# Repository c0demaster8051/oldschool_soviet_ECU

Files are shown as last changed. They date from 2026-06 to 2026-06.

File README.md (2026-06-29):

# ЭБУ на советской элементной базе

Идея сделать такой девайс на древней элементной базе появилась исключительно из любви к искусству,
Хотелось собрать что-то красивое, применимое в реальной жизни и немного подкачать скилл.
Мне нравятся простые и дубовые детали в красивых керамических корпусах, но собирать устройство
которое будет просто лежать на полке и собирать пыль (как новодельные сборки ZX Spectrum) мне не интересно.
Считаю что вещь должна работать и приносить пользу.

### Внимание!

Блок уже давно спроектирован и собран, работает на машине уже более года, просто сейчас решил выложить его
чтобы не потерять схемы и код проекта (как обычно раскиданный по разным дискам и флешкам). Постепенно я буду
приводить схемы к понятному для окружающих виду и заливать сюда.

### Коротко о возможностях:

- Максимальные обороты:  
10000 для задающего диска 60-2 (ВАЗ, ЗМЗ и др.), до 15000 для диска 36-2 (toyota)

- Точность управления:
дискретность времени открытия форсунок и выдачи импульса зажигания - 1 мкс.
Момент выдачи искры определяется аппаратно отдельной схемой, которую контроллер просто "взводит"
перед использованием, благодаря чему момент зажигания выдаётся абсолютно точно независимо от
времени реакции контроллера.

- Аналоговые входы - 5 каналов АЦП с разрядностью 11 бит, один из которых с устройством выборки и хранения
для датчика абсолютного давления, выполняет измерение с жёсткой привязкой к положению коленвала. 
Оставшиеся 4 канала:  
Датчик положения дросселя,  
Напряжение бортсети (для коррекции динамической производительности форсунок от напряжения питания),  
Датчик температуры двигателя,  
Датчик температуры воздуха

- Дискретные выходы:  
4 линии на шаговый РХХ,  
4 независимых линии для управления реле бензонасоса и прочими механизмами

### Hardware:

Из-за сильно ограниченных вычислительных способностей элементной базы тех лет, блок пришлось делать
на двух контроллерах, ведущий и ведомый, далее будем называть их master и slave.

Slave контроллер выполняет самую сложную работу в реальном времени, такую как синхронизация на задающий
диск шкива коленвала, выдача импульсов зажигания, открытие форсунок с учётом фазы впрыска и взятие значения
с датчика абсолютного давления с жёсткой привязкой к положению коленвала. Программа для слейва написана
на ассемблере, вылизана по тактам и микросекундам, благодаря чему со стандартным задающим диском 60-2 (ВАЗ, ЗМЗ)
блок успевает корректно управлять двигателем до 10000 оборотов в минуту. С диском 36-2 максимальные обороты
увеличиваются до 15000.

Таймеры управляющие зажиганием и форсунками тактируются с частотой 1 МГц, соответственно точность момента
искрообразования и длительности впрыска получается 1 микросекунда. Для сравнения на ВАЗовском ЭБУ "Январь"
точность времени впрыска и момента зажигания 6 мкс.

Slave общается с мастером через отдельный маленький буфер на дискретной логике, постоянно получая от мастера
время впрыска, момент зажигания, фазу впрыска. При старте блока slave получает фиксированные параметры,
обычно не изменяемые в процессе работы блока, например фазу измерения значения ДАД, базовые настройки
синхронизации (такие как полное число зубов шкива, число пропущенных, порог срабатывания при поиске пропуска).
Обратно он отдаёт измеренное время оборота коленвала в микросекундах и некторые флаги.

Мастер в свою очередь выполняет расчёт топливоподачи и зажигания асинхронно от вращения двигателя,
с фиксированной частотой 122 Гц (частота получения результата измерения канала ДАД). В конце расчёта он
передаёт ведомому (slave) контроллеру актуальные значения по топливу и зажиганию. Из-за фиксированной
и относительно небольшой скорости выполнения расчётов программа для мастера написана на СИ.

Блок состоит из 4 плат. Детальное описание каждой, исходные файлы плат и исходники прошивок (для плат с
контроллерами) лежат в отдельных папках, каждая под свою плату. Содержимое папок будет постоянно дополняться,
на данный момент можно примерно понять конструкцию и принцип дествия.

Для смельчаков и просто странных личностей, решивших собрать плод моего больного воображения:
дождитесь когда я подготовлю полное описание)) будут gerber файлы, 3D модели корпуса и подробная инструкция
по сборке и прошивке.

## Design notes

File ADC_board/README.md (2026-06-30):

# Плата АЦП и буфера межконтроллерного обмена

<p align="center">
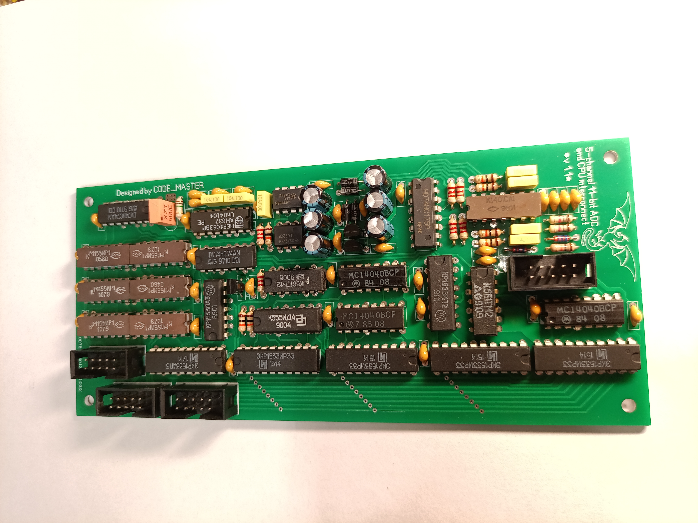
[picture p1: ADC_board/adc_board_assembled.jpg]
Assebled
  
</p>

На данной плате расположен 5-канальный АЦП и буфер для взаимодействия
master и slave контроллеров, обмен с ведущим процессором выполняется по
классической 8-разрядной мультиплексированной шине адреса/данных. Адреснужного
регистра защёлкивается линией управления ALE, после чего можно выполнять
чтение или запись в регистры.

### Описание АЦП:

АЦП интегрирующего типа, разрядностью 11 бит с диапазоном входных напряжений
от GND до VCC. накопление результата длится 2049 тактов, при частоте тактирования
всей схемы 250 КГц АЦП выдаёт результат со скоростью 122 герц. Тактовый генератор
собран на керамическом резонаторе 500 КГц, далее эта частота делится на 2.
АЦП имеет один общий счётчик циклов измерения на микросхеме CD4040 и два
отдельных накопителя импульсов с интеграторов тоже на CD4040. По переполнению
счётчика циклов измерения результат из двух накопителей пишется в выходные
регистры 1533ир33.

Один из накопителей - выделенный канал АЦП для датчика абсолютного давления,
с аналоговой схемой sample&hold для фиксации мгновенного значения сигнала.
Свежий результат измерения с этого канала доступен в каждом новом прерывании от АЦП.
Второй накопитель обслуживает 4 мультиплексных канала. Каждый из этих каналов имеет
свой непрерывно тактируемый интегратор и счётчик, последовательно переключающий каналы.
Мультиплексный канал при помощи цифрового коммутатора выбирает с какого из интеграторов
он будет накапливать импульсы.

Мультиплексных канала 4, поэтому их фактическая частота опроса - 122/4 = 30.5 Гц.
Результат измерения обоих каналов доступен через три 8-битных регистра, в которых
11 бит отводится под результат выделенного АЦП, 11 бит для мультиплексного и 2 бита
для указания номера только что измеренного мультиплексного канала.

Адрес и формат данных в регистрах:
0x00 - младшие 8 бит мультиплексного канала целиком.
0x01 - старшие 3 бита этого регистра (биты 5, 6, 7) являются старшими битами
результата мультиплексного канала. Биты 3 и 4 - номер только что измеренного
мультиплексного канала. Младшие 3 бита (0, 1, 2) - старшие для выделенного канала.
0x02 - младшие 8 бит выделенного канала.

### Описание буфера межконтроллерного обмена:

Буфер обмена представляет собой 6 сдвиговых 4-битных регистрана микросхемах 74ls95,
суммарной ёмкостью 3 байта. В зависимости от режима блок данных сдвигается или ведущим
(master) контроллером, параллельным сдвигом, по половинке байта в 6 подходов, или
последовательно по одному биту ведомым (slave) контроллером. Режим работы буфера выбирается
slave контроллером, и переключается в последовательный режим при обращении slave к буферу.

После обмена ведомый контроллер переводит буфер в параллельный режим, вызывая этим
прерывание у ведущего, и оставляет его в этом режиме до появления сигнала готовности
новых данных от ведущего. Для чтения данных из буфера master контроллером отведён адрес
0x03, байты вычитываются из буфера 4-битными посылками, расположенными в старших битах
на шине данных. Первым чтением получаем из буфера младшую половину байта (сдвигаем
результат чтения на 4 бита вправо), вторым чтением получаем старшую половину (обнулить
в результате чтения младшие 4 бита и наложить на предыдущий считанный результат.)
аналогичным образом читаются оставшиеся 2 байта, суммарно 6 циклов чтения.

Запись в буфер выполняется аналогичным образом, но по адресу 0x02, сначала записываемый
байт сдвигается влево на 4 бита, пишется в порт, после чего байт пишется в порт без сдвига,
и так аналогично для оставшихся двух байт.

Чтобы подать slave контроллеру сигнал о готовности данных - необходимо выполнить пустую
запись по адресу 0x03, этим мы взводим триггер, который выдаёт ведомому активный уровень
на линии MRDY. После этого нам остаётся ждать, пока ведомый выйдя из очередного прерывания
увидит этот запрос, займёт буфер, выполнит обмен данными и в конце переводёт буфер обратно
в параллельный режим, тем самым вызвав прерывание у ведущего. Если не сообщать slave контроллеру
о готовности - данные так и будут лежать в буфере и мы можем прочитать их обратно,
это может быть полезно для самотестирования схемы при запуске устройства.

## Описание разъёмов платы:

<p align="center">
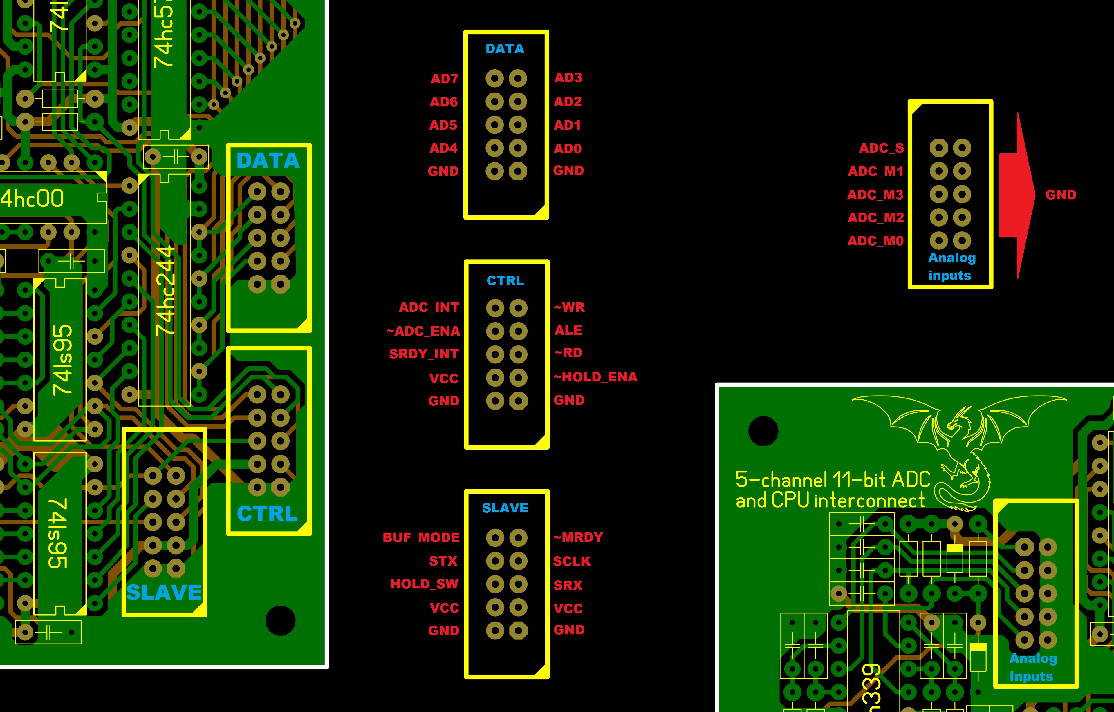
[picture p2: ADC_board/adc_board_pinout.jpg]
Распиновка
  
</p>

### Разъёмы DATA и CTRL идут на плату master контроллера

- Линии AD0-AD7 - мультиплексная шина адреса/данных

- ADC_INT - прерывание АЦП. При непрерывной работе АЦП (ADC_ENA==0)
в процессе измерения находится в высоком уровне, после чего по нулю
длительностью 4 мкс происходит запись в выходные регистры АЦП.
С переходом из 0 в 1 начинается новый цикл измерения. Нарастающий фронт
этого сигнала вызывает прерывание у ведущего процессора.
При непрерывной работе измерения выполняются со стабильной частотой 122 Гц,
мультиплексные входы из-за последовательного опроса отдают данные с частотой
в 4 раза ниже, примерно 30.5 раз в секунду.

- ~ADC_ENA - сигнал разрешения работы АЦП, активный уровень 0.
При снятии этого сигнала АЦП  выполняет полное измерение, после чего
выход ADC_INT принимает уровень 0, в котором находится до очередного
разрешения работы АЦП. Отключение АЦП позволяет незначительно снизить
потребление тока, т.к. на него завязана схема полученния дополнительных
питающих напряжений для входных ключей, усилителей и компараторов.

- SRDY_INT - прерывание от ведомого процессора. Этот-же сигнал выведен
на другой разъём как BUF_MODE. При чтении ведомым процессором данных из буфера,
этим сигналом буфер переводится в последовательный режим, после чего 3 байта
данных сдвигаются и побитово читаются ведомым процессором. После чтения данных
и (опционально) записи в буфер своих - сигнал переводится в 1, переводя буфер в
параллельный режим и сообщая ведущему процессору о готовности.
Нарастающий фронт этого сигнала вызывает прерывание у ведущего процессора.

- ~WR - сигнал записи для параллельной шины, активный уровень 0.

- ALE - сигнал защёлкивания адреса в дешифратор, запись длится в течении уровня 1.

- ~RD - сигнал чтения для параллельной шины, активный уровень 0.

- ~HOLD_ENA - Сигнал разрешения работы схемы sample&hold для выделенного канала АЦП,
при работе которой сигнал берётся с привязкой к положению коленвала. Активный уровень 0.
При отключении выделенный вход АЦП подключается аналоговым коммутатором напрямую.

### Разъём SLAVE идёт на плату ведомого контроллера.

- BUF_MODE - то-же что и SRDY_INT, смотри описание выше. Схема с открытым коллектором.
Долгое удержание этой линии в состоянии 0 ведомым процессором (в случае его зависания)
или ведущим процессором вызывает запуск простейшего аналогового watchdog таймера
на плате ведомого процессора, вызывая его сброс и заставляя отпустить эту линию.

- STX - последовательный выход данных от ведомого процессора для записи в буфер.

- HOLD_SW - фиксация уровня сигнала схемой sample&hold ведомым процессором
в заданный угол поворота коленвала. Выполняется простой переход этой линии в противоположное
состояние, меняя местами одну группу конденсаторов, непрерывно фиксирующих входной сигнал,
с другой группой, чьё "зафиксированное" напряжение подаётся на выделенный вход АЦП.

- ~MRDY - сигнал о готовности команды и данных в буфере на ведомый процессор от ведущего,
активный уровень 0. В фоновом режиме между прерываниями ведомый процессор опрашивает этот сигнал,
и по его активации переводит буфер в последовательный режим для взаимодействия с ним.

- SCLK - тактирование последовательных данных от ведомого процессора. Сдвиг данных в буфере
выполняется по спадающему фронту этого сигнала.

- SRX - последовательный вход данных ведомого процессора для чтения из буфера.

### Разъём Analog inputs идёт на силовую плату.

- ADC_S - выделенный вход под датчик абсолютного давления, с фиксацией сигнала схемой sample&hold.

- ADC_M1 -  мультиплексный вход под датчик положения дросселя.

- ADC_M3 - мультиплексный вход для контроля напряжения бортсети. Делитель напряжения находится на
силовой плате. Одна дискрета АЦП соответствует 10 милливольтам входного напряжения. Для примера,
значение АЦП 1260 будет соответствовать 12.6 вольтам бортсети.

- ADC_M2 - мультиплексный вход с подтяжкой 1 КОм для терморезистора датчика температуры двигателя.

- ADC_M0 - мультиплексный вход с подтяжкой 1 КОм для терморезистора датчика температуры воздуха.

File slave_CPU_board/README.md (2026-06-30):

# Плата slave контроллера

<p align="center">
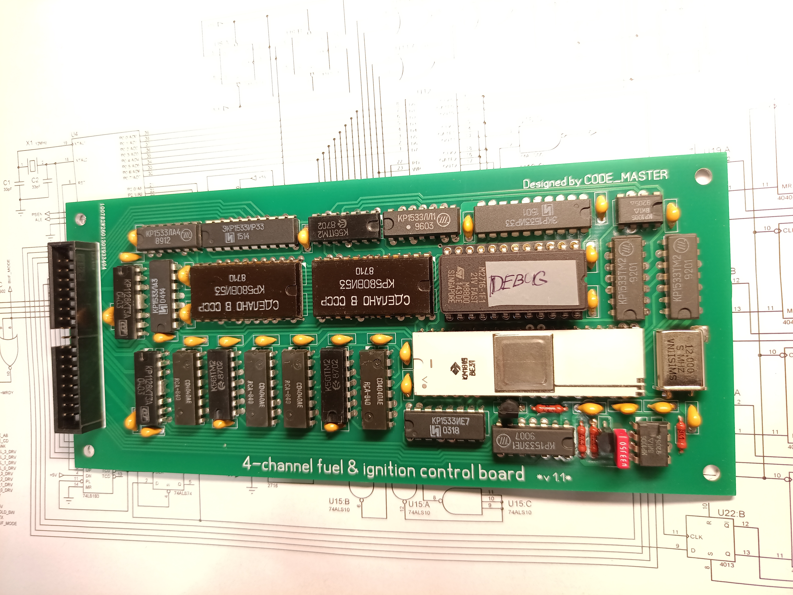
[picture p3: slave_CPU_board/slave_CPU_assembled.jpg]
Assebled
  
</p>

Плата ведомого контроллера собрана на intel 8031 (русский аналог 1816ве31 или его КМОП
версия 1830ве31) с тактовой частотой 12 МГц. Из основного имеет на борту 2 Кб внешней
ПЗУ памяти программ, 2 микросхемы программируемых таймеров intel 8253 (русский аналог 580ВИ53),
работающих с тактовой частотой 1 МГц (точность отсчёта времени соответственно 1 мкс) и таймеры
открытого состояния ключей зажигания на мелкой логике. Все остальные элементы будут описаны далее.

### Алгоритм синхронизации по ДПКВ

Самый главный элемент платы - схема синхронизации на ДПКВ. Вход сигнала ДПКВ подключен
к триггеру шмитта на таймере ne555, для лучшей помехоустойчивости. Инвертированный
сигнал с выхода триггера идёт на постоянно тактируемый D-триггер 1533тм2, который
синхронизирует фронты входного сигнала с тактовым сигналом, в качестве которого используется
сигнал ALE контроллера с частотой 2 МГц. Следующий триггер подключен тактовым входом к выходу
первого триггера, и ставится в единицу при нарастающем фронте входного сигнала, но при этом
асинхронный вход R этого триггера подключен к ALE, таким образом, установившись в состояние 1
по нарастающему фронту ALE, через 0.25 микросекунды триггер сбрасывается низким уровнем на ALE.
В результате этот триггер даёт короткие положительные импульсы по нарастающему фронту
входного сигнала (или соответственно по спадающему перед формирователем на ne555).
Эти короткие импульсы используются схемой формирования сигнала на зажигание, которая
будет описана далее.

Синхронизированный с сигналом ALE входной сигнал идёт на тактовый вход D-триггер соседней
микросхемы 1533тм2, инверсный выход которого подключен на его вход данных. Таким образом
каждый положительный фронт входного сигнала прямой и инверсный выходы триггера меняют
состояние на противоположное. Эти выходы идут на входы прерываний контроллера INT0 и INT1.
Эти входы настроены так, что низкий уровень на них останавливает внутренний таймер контроллера
с соответствующим номером и вызывает прерывание. Таймеры считают с частотой 1 МГц.
Для примера, спадающий фронт на входе INT0 вызывает соответствующее прерывание, а низкий
уровень на нём моментально останавливает таймер 0. В свою очередь противоположный сигнал на INT1
своим высоким уровнем запускает таймер 1. В данной ситуации в прерывании INT0 контроллер считывает
период из остановленного таймера 0 и обнуляет его, чтобы при очередном фронте сигнала ДПКВ
запустить этот таймер и считать результат измерения из таймера 1 (они работают по очереди).

Каждый новый измеренный период сравнивается с предыдущим, и в случае если только что измеренный
период намного больше предыдущего - значит мы наткнулись на пропуск зубов задающего диска коленвала,
и зуб вызвавший это прерывание, первый после пропуска, будет точкой отсчёта с номером 0.

В каждом следующем прерывании счётчик зубов увеличивается, и выполняется проверка, следует ли
исполнить какое-либо действие. Для примера, такими действиями является впрыск топлива, переключение
схемы sample&hold для АЦП датчика давления, или подготовка к выдаче импульса зажигания.
на ВАЗовском диске с формулой 60-2 зубья идут через каждые 6 градусов поворота коленвала,
соответственно с такой дискретностью идёт исполнение событий по ходу вращения двигателя.
Дальнейшее описание этих событий начнём от простого к сложному.

### Sample&hold

Самое простое - переключение схемы фиксации уровня сигнала датчика давления. Для этого используется
бит 7 регистра GPIO, в качестве которого используется 1533ир33, подключенный к внешней шине данных.
Изменение уровня на противоположное переключает группы конденсаторов на плате АЦП, подключая ко входу
компаратора АЦП конденсаторы со свежим "зафиксированным" уровнем сигнала.

### Синхронизированный впрыск топлива

Следующее по сложности - впрыск топлива. Для этого используются таймеры с номерами 1 и 2 микросхем
580ви53, с двух микросхем соответственно доступно 4 раздельных независимых выхода на форсунки. Запуск
этих таймеров на выдачу импульса открытия форсунок выполняется строго синхронно по шкиву, в зависимости
от режима впрыска (фазированный или попарный) запускается по одному или сразу по 2 таймера. Таймеры
настроены в такой режим, что открывают форсунку и считают время сразу после записи периода в таймер.
Дешифрация адреса для обращения к таймерам устроена таким образом, что можно одним разом выполнить
запись сразу в 2 таймера для попарного режима впрыска.

### Асинхронный впрыск

Таймер 0 одной из микросхем используется отдельно для асинхронного впрыска, и подключен на входы
сразу к 4 промежуточным элементам И-НЕ, благодаря чему способен открывать сразу все форсунки
при запуске отсчёта. Асинхронный впрыск выполняется без привязки к положению коленвала,
сразу-же при поступлении команды с ведущего процессора.

### Управление системой зажигания

Самая сложная часть - система зажигания. Таймер 0 одной из 580ви53 используется для точного отсчёта
смещения от зуба ДПКВ для выдачи импульса зажигания. Для выбора момента зажигания используется
номер зуба шкива и смещение относительно него с точностью 1/256 часть от периода между зубами.
Запись периода в этот таймер не запускает его сразу, а всего-лишь взводит схему разрешения счёта,
в момент записи блокирующую таймер нулём по входу GATE, и которая в свою очередь аппаратно запускает
таймер единицей по входу GATE на ближайшем импульсе ДПКВ. Таймер сразу-же начинает считать, и в конце
счёта выдаёт импульс зажигания, запуская отдельные следующие за ним выходные таймеры на рассыпухе
(микросхемы 561тм2 и 561ие20). Контроллер своими линиями порта P1 может управлять длительностью этого
импульса (старшая тетрада P1 подключена к счётчику с переменным коэффициентом деления) и определяет,
на какие из 4 выходов пойдёт этот импульс зажигания (Младшая тетрада P1). Таким образом, аппаратная
привязка запуска таймера зажигания позволяет устранить задержки и достичь высокой угловой и временной
точности импульса зажигания. Для примера, 1 микросекунда (дискретность отсчёта таймера) на 10 тысячах
оборотов коленвала в минуту будет соответствовать его углу поворота на 0.06 градуса.

### Цепи согласования с остальной схемой

Из дополнительной обвязки на плате имеются силовые ключи 1128кт3 для управления ключами форсунок
и выдачи импульсов с напряжением бортсети на коммутаторы, простейшая схема сброса контроллера и
по совместительству watchdog таймер на ещё одной микросхеме ne555, защёлка адреса на регистре 1533ир33,
схема согласования контроллера с буфером межпроцессорного обмена, предделитель тактовой частоты
на микросхеме 1533ие7 для таймеров длительности импульса зажигания, и ранее описанный выходной порт
GPIO на ещё одной микросхеме 1533ир33, старший бит которого идёт на плату АЦП а младшие 6
на силовую плату для управления исполнительными устройствами (бензонасос, РХХ и прочее).

С текущей реализацией программы плата способна работать с ВАЗовским задающим диском 60-2
до оборотов около 10 тысяч, с диском 36-2 максимальные рабочие обороты пропорционально возрастают,
достигая 16 тысяч об/мин.

## Протокол обмена с ведущим:

Ведущий (master) контроллер пишет в буфер обмена команду и данные, и выполнив запись
по определённому адресу взводит сигнал MRDY, сообщающий ведомому (slave) контроллеру
о наличии команды в буфере. Их список приведён далее:

[00]-[##]-[##] - status  
Если первый байт (команда) ==0 - остальные байты не читает.  
В ответ отправляет в первом байте старшая тетрада - флаги,  
младшая тетрада и следующие 2 байта - период оборота.  
20 бит, little endian  
флаги в старшей тетраде:  
3 - comm_err_flag - ошибка данных предыдущей команды (сброс после чтения)  
2 - sync_err_flag - сбой синхронизации (сброс после чтения)  
1 - rev_parity_flag - чётный/нечётный оборот, для алгоритма работы без датчика фаз  
0 - sync_reach_flag - начальная синхронизация выполнена (двигатель крутится)

[11]-[num]-[offset] - ignition  
num - номер зуба, на котором взводится схема выдачи импульса зажигания.  
Следующий зуб ДПКВ аппаратно запускает отсчёт таймера.  
offset - дробное смещение от начала зуба по модулю 256.

[22]-[fuel_hi]-[fuel_lo] - sync_fuel  
Время впрыска в микросекундах, 16 бит, little endian  
Исполняется постоянно синхронно по шкиву.

[33]-[fuel_hi]-[fuel_lo] - async_fuel  
Асинхронный впрыск всеми форсунками в микросекундах, разовое исполнение  
в момент прихода команды. 16 бит, little endian

[44]-[adc_num]-[fuel_num] - phase_ctrl  
adc_num - фаза измерения АЦП, момент захвата сигнала схемой sample&hold  
fuel_num - фаза впрыска, на каком зубе шкива откроется форсунка

[55]-[gpio]-[ign_ctrl] - gpio_ctrl  
gpio - младшие 6 (0-5) бит идут на дискретные порты вывода  
бит 6 - включение фазированного впрыска при единице  
бит 7 - инверсия фазы, разовое исполнение при единице  
ign_ctrl - управление зажиганием, старшая тетрада - инверсное значение предделителя  
все 0 соответствуют максимальному времени открытого ключа в 5.12 мс  
младшая тетрада - маска разрешения каналов зажигания, можно использовать для  
отключения одного цилиндра и поиска фазы по времени оборота

[66]-[redline_hi]-[redline_lo] - redline_period  
Минимальный период оборота в микросекундах, 16 бит, little endian  
Если период оборота меньше этого значения - подача зажигания и (опционально) топлива отключается.  
Следующая команда определяет, как именно это будет происходить.

[77]-[##]-[redline_preset] - redline_ctrl  
Переданные этой командой значения используются для счётчиков, отключающих на указанное  
число оборотов топливо и зажигание. Счётчики отрабатывают последовательно, сначала считает  
пропуски топлива, потом зажигания. Таким образом можно перед возобновлением зажигания  
наливать немного бенза и бахать его крутя мотор в отсечке.  
redline_preset - старшая тетрада - счётчик пропусков впрыска,  
младшая тетрада - счётчик пропусков зажигания после включения впрыска

[DD]-[sync_count_num]-[~sync_count_num] - sync_count  
sync_count_num - количество зубов шкива (для шкива 60-2 будет 58)  
байты данных передаются как прямой и инверсный

[EE]-[sync_half_num]-[~sync_half_num] - sync_half  
sync_half_num - количество зубов половины оборота (для шкива 60-2 будет 30)  
байты данных передаются как прямой и инверсный

[FF]-[sync_start_mult]-[~sync_start_mult] - sync_mult  
sync_start_mult - порог срабатывания при поиске пропуска на шкиве  
порог срабатывания считается как if(((curr_per*sync_start_mult)>>8) >= prev_per) sync_found();  
где curr_per - только что измеренный, а prev_per - предыдущий период между импульсами ДПКВ  
байты данных передаются как прямой и инверсный

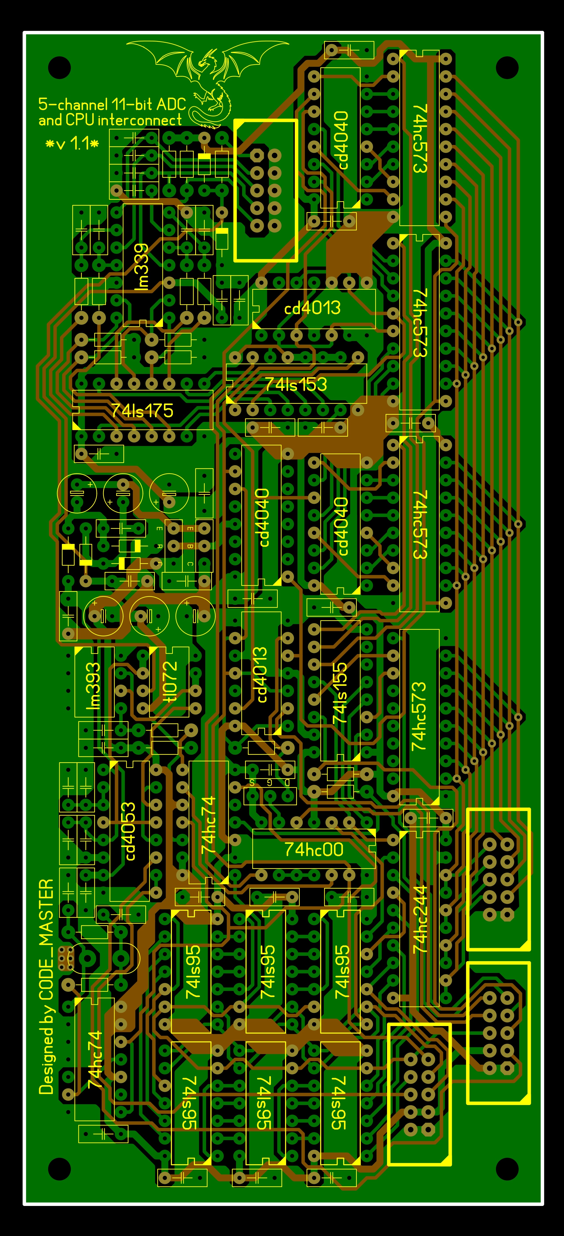
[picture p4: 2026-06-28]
ADC_board.jpg

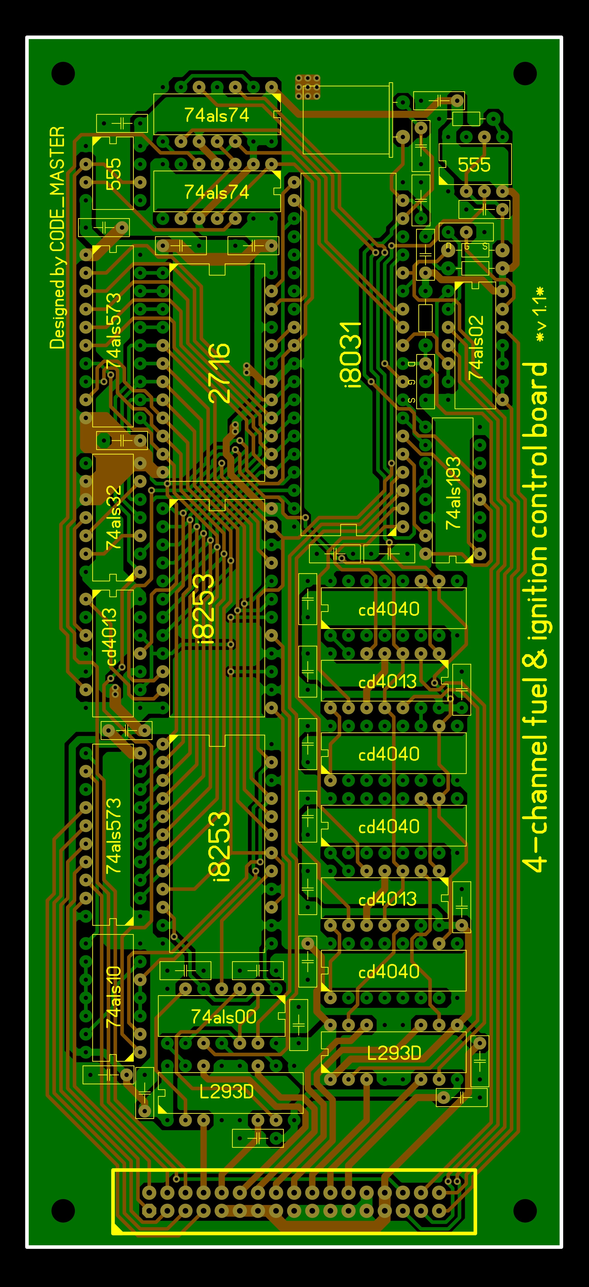
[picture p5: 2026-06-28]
slave_CPU_board.jpg

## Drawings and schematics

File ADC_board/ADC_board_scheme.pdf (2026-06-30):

U10:A | 4013
U10:B | 4013

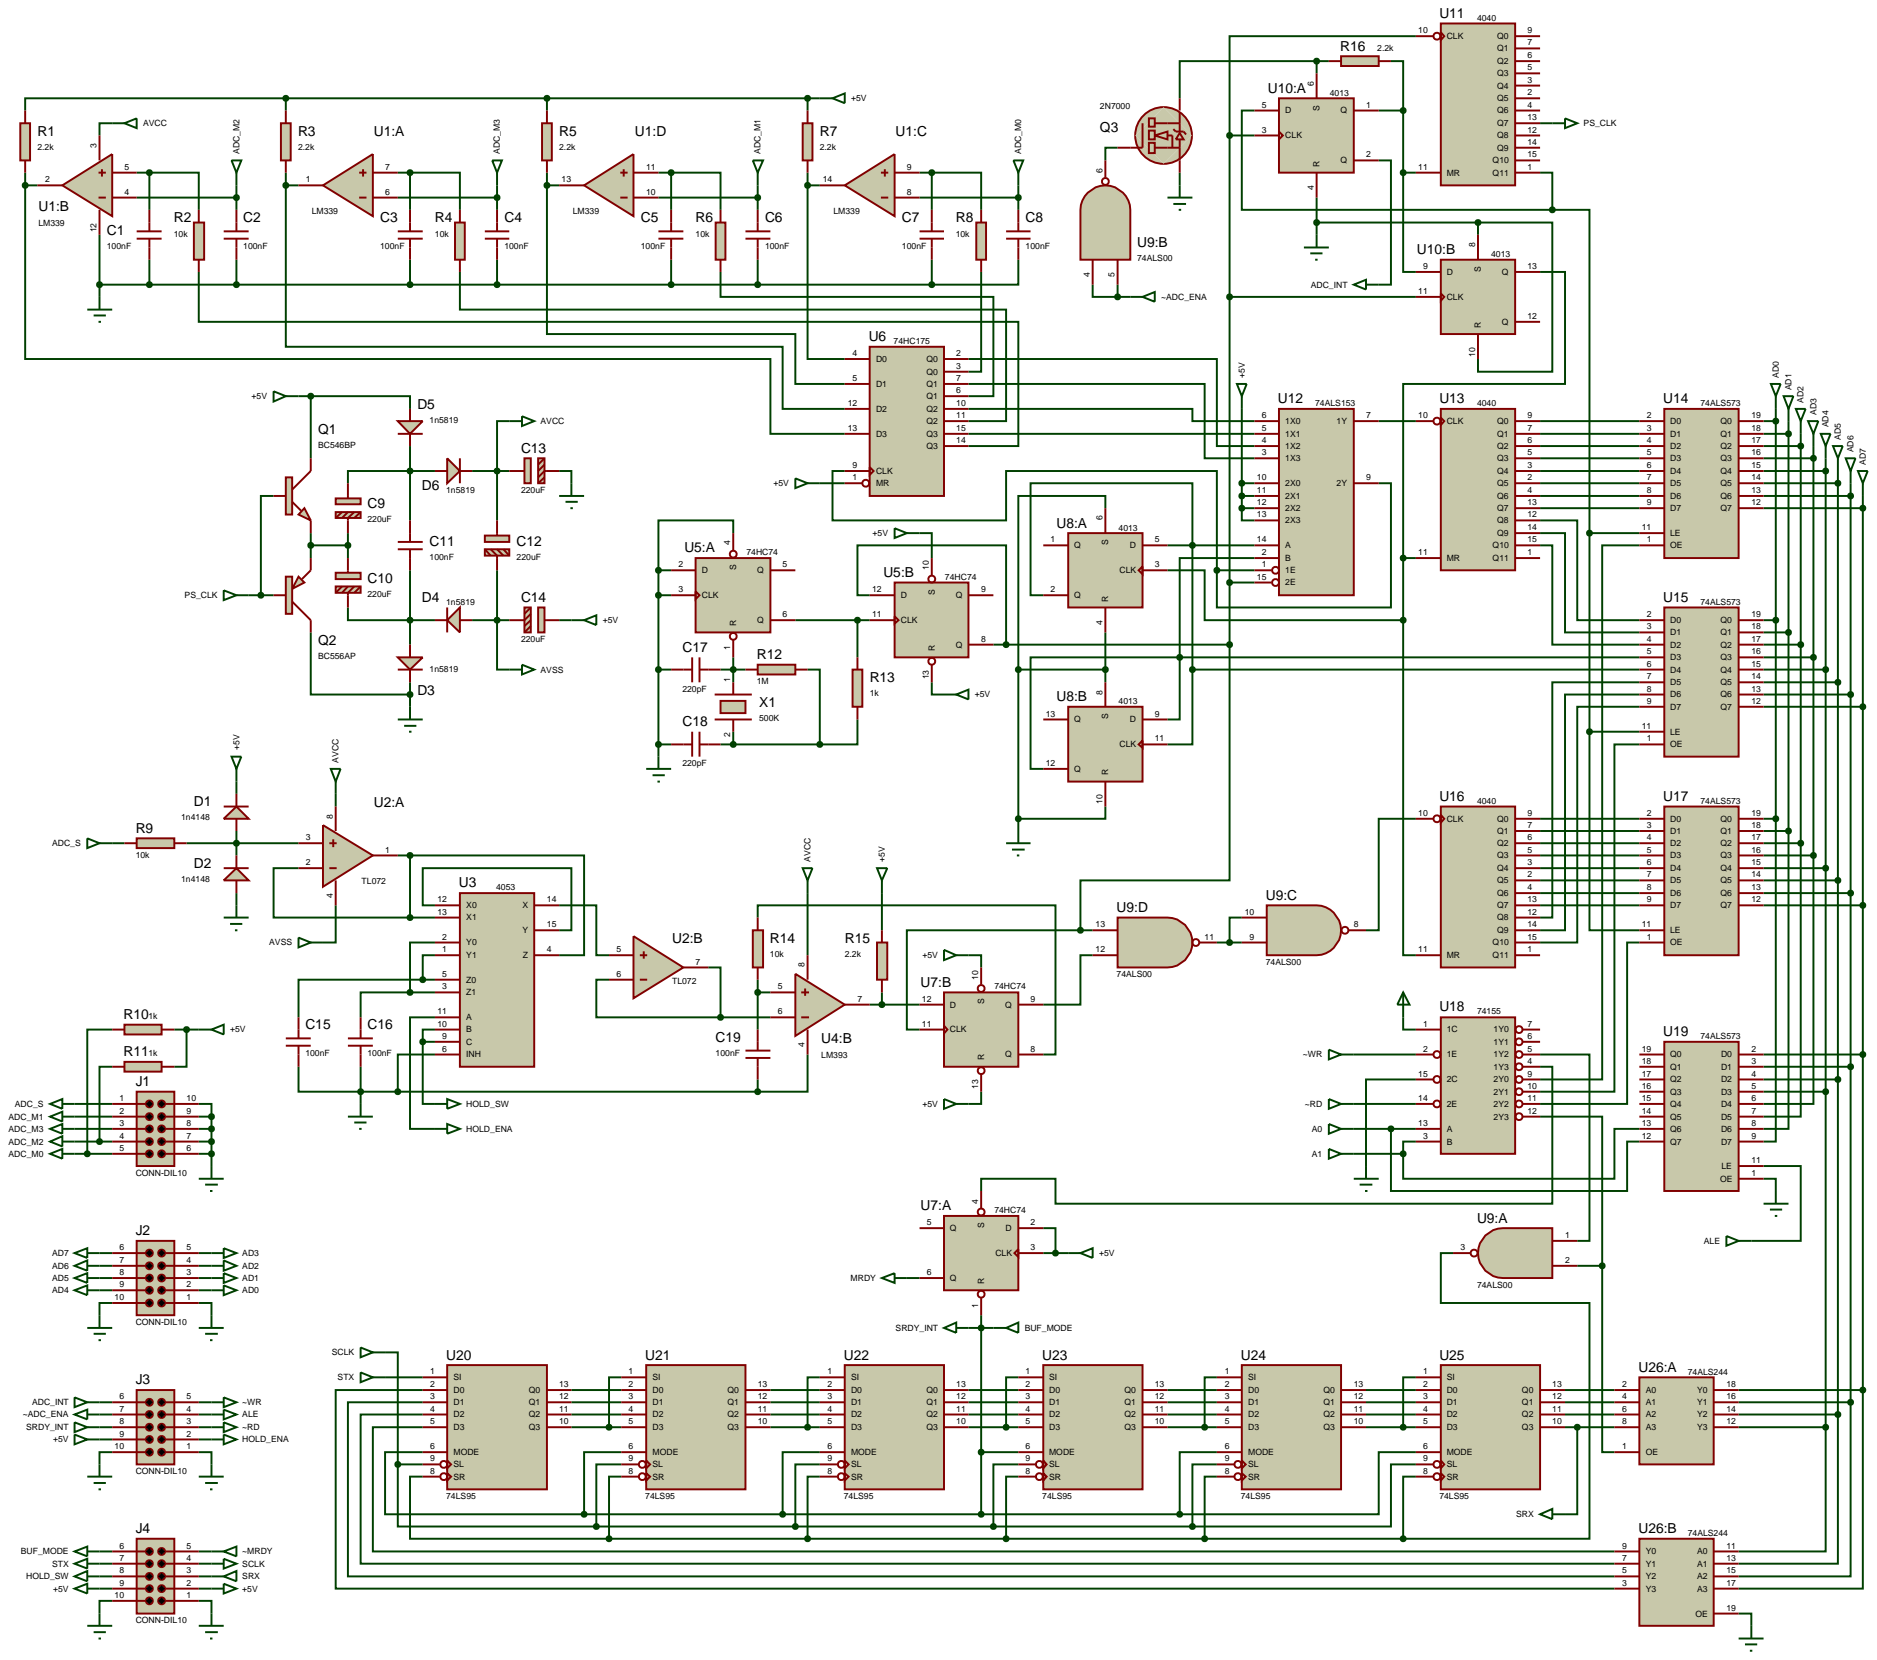
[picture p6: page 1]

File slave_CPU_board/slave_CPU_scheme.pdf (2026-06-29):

U12

U4

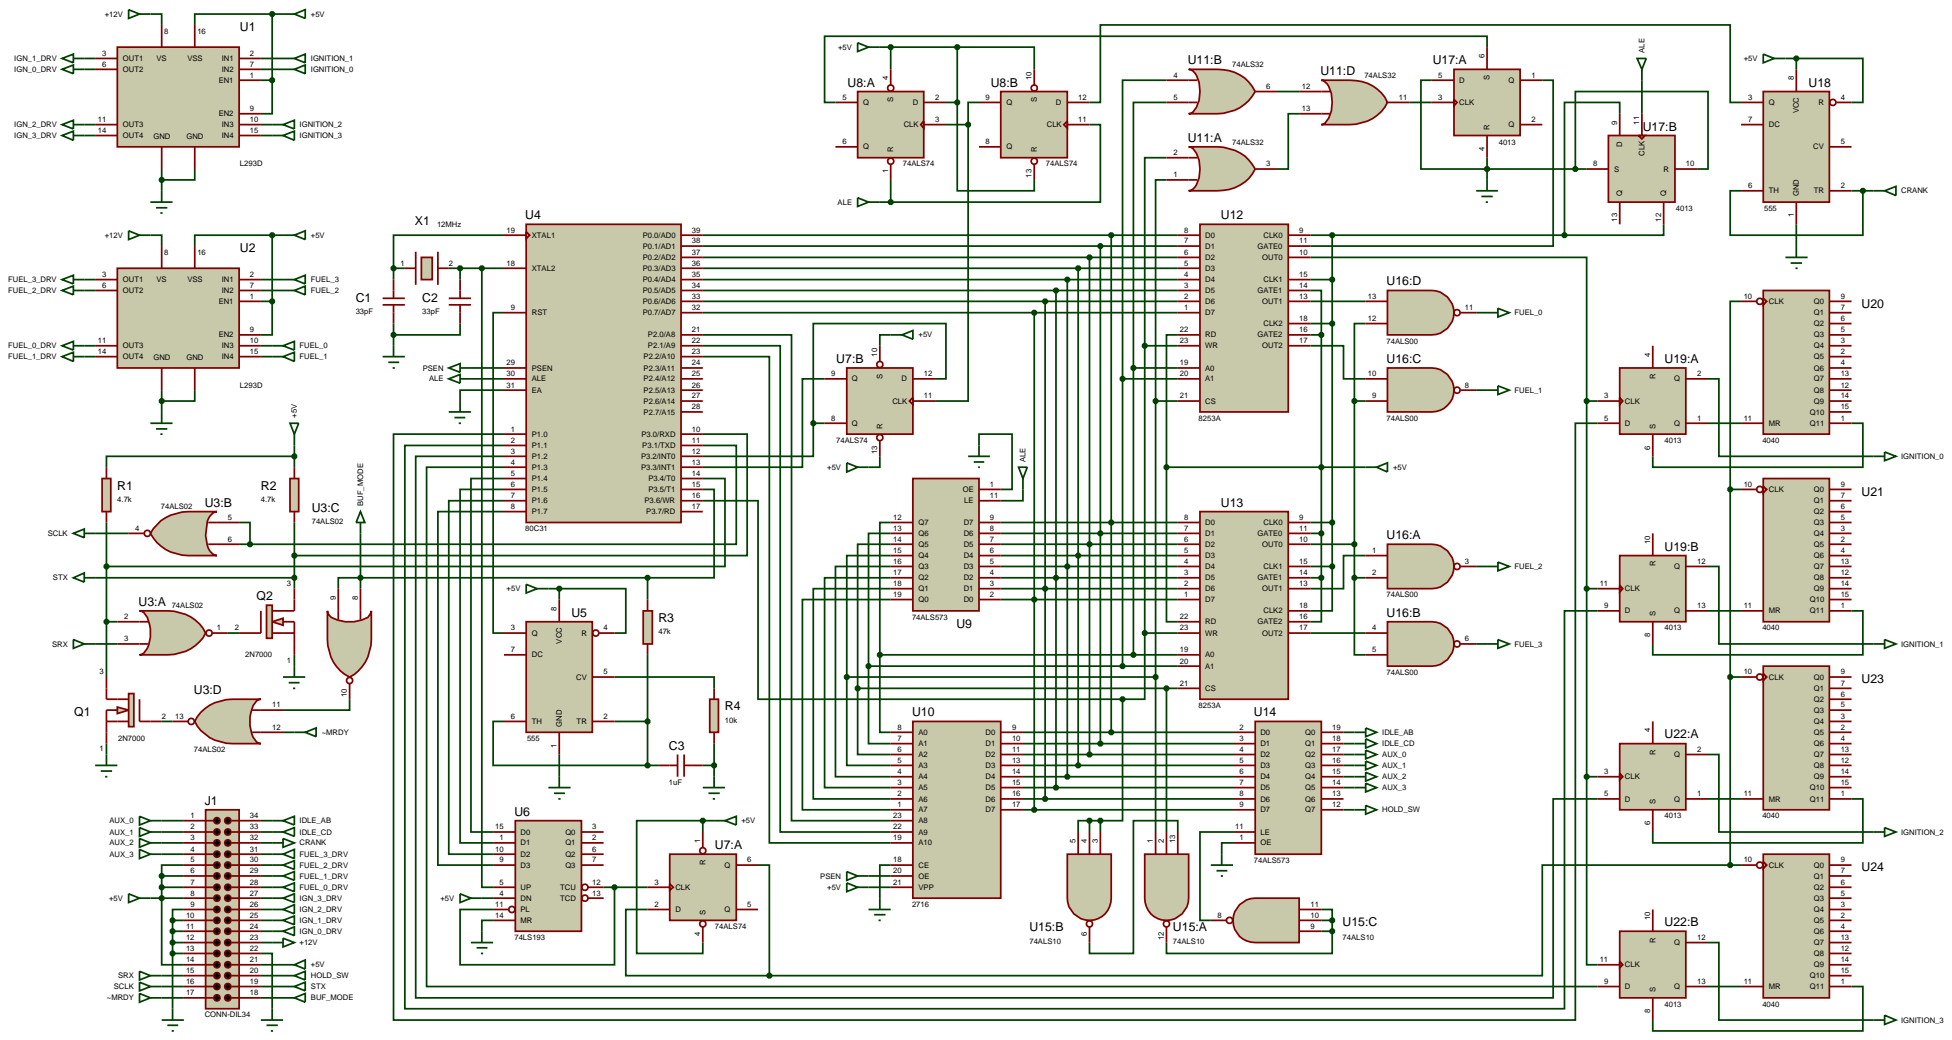
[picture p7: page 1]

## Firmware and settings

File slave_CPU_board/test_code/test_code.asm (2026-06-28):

; настройка синхронизации по шкиву
sync_start_mult equ 30h
sync_half_num equ 31h
sync_count_num equ 32h

; основные переменные
ign_num equ 33h
ign_offset equ 34h
ign_ctrl equ 35h
fuel_num equ 36h
fuel_lo equ 37h
fuel_hi equ 38h
adc_num equ 39h

; накопленный период оборота скидывается сюда
period_lo equ 3Ah
period_mi equ 3Bh
period_hi equ 3Ch

; в процессе обмена по шине обновляются временные значения,
; которые потом в прерывании заменят собой постоянные
; в начале следующей половины оборота
ign_num_temp equ 3Dh
ign_offset_temp equ 3Eh
fuel_num_temp equ 3Fh

; временное хранение состояния GPIO
; старший бит меняется прерыванием
gpio_reg equ 40h

; настройки отсечки
redline_lo equ 41h
redline_hi equ 42h
redline_preset equ 43h
redline_fuel_count equ 44h
redline_ign_count equ 45h




; адрес регистра флагов не менять! он связан с перечисленными ниже
; прямоадресуемыми битами
flag_reg equ 20h
rev_half_flag equ 00h ; в какой половине оборота относительно пропуска находится шкив
phase_allow_flag equ 01h ; разрешение перехода в фазированный впрыск
redline_fuel_flag equ 02h ; флаг отсечки
redline_ign_flag equ 03h ; флаг отсечки
; следующие 4 флага доступны для чтения командой статус
sync_reach_flag equ 04h ; признак вращения движка и достижения синхронизации
rev_parity_flag equ 05h ; чётный/нечётный оборот для фазированного впрыска
sync_err_flag equ 06h ; ошибка синхронизации, если число зубов до пропуска не совпало
comm_err_flag equ 07h ; неверная команда или контрольная сумма при обмене данными






org 0h
ajmp init


org 03h ; Внешнее прерывание INT0
; Входы INT0 и INT1 подключены к комплементарным выходам триггера
; схемы синхронизации по ДПКВ, поэтому их состояние всегда противоположно.
; прерывание вызывается падающим фронтом на выводе INT0,
; низкий уровень на нём останавливает таймер 0, и запускает таймер 1
; мы можем считать период из остановленного и сбросить его для нового отсчёта
ajmp tim_0_rdy_int


org 0bh ;Пpepывaниe oт тaймepa 0
; переполнение любого из таймеров обозначает остановку двигателя
; и срыв синхронизации, после чего при повторной прокрутке стартером
; надо снова ловить пропуск зубов на шкиву. сбрасываем бит синхронизации
; останавливаем таймер и пишем в него максимальное значение
clr TR0
mov TH0,#0FFh
sjmp tim_ovf_end


org 13h ; Внешнее прерывание INT1
; аналогично прерыванию INT0, только здесь обслуживаем таймер 1
ajmp tim_1_rdy_int


org 1bh ; Прерывание от таймера 1
; аналогично таймеру 0
clr TR1
mov TH1,#0FFh
sjmp tim_ovf_end


org 23h ; прерывание от UART
; Не используется
reti


org 24h
tim_ovf_end:
clr sync_reach_flag ; сбрасываем флаг синхронизации
; и обновляем данные
mov ign_num,ign_num_temp
mov ign_offset,ign_offset_temp
mov fuel_num,fuel_num_temp
reti


org 40h
; R0 - полный номер зуба
; R1 - "симметричный" номер зуба
; R2, R3, R4 - накопитель периода оборота
; R5 - общая переменная для расчёта
; R6, R7 - предыдущее время между зубами шкива
tim_1_rdy_int:
push PSW
push ACC
push B
push DPL
; выбираем первый банк регистров
mov PSW,#08h
; прибавляем новое значение к накопителю
; на последнем зубе в накопителе будет полный период оборота двигателя
mov A,R2
add A,TL1
mov R2,A
mov A,R3
addc A,TH1
mov R3,A
clr A
addc A,R4
mov R4,A
; теперь сравниваем свежее значение с предыдущим для поиска пропущенных зубов
; для этого свежее значение умножаем на  уменьшающий коэффициент
mov A,TL1
mov B,sync_start_mult
mul AB
mov R5,B
mov A,TH1
mov B,sync_start_mult
mul AB
add A,R5
cpl A
mov R5,A ; теперь в R5 инвертированный младший байт
clr A
addc A,B
cpl A
xch A,0Dh ; xch R5
; а теперь в R5 инвертированный старший байт
; а в аккумуляторе инвертированный младший
; складываем с младшим предыдущего результата
add A,R6 ; сумма нас не интересует, нужен только перенос
mov A,R5 ; складываем старший инвертированный
; со старшим предыдущего измерения
addc A,R7 ; и если нет флага переноса - значит текущее измерение
; даже с учётом понижающего коэффициента оказалось больше предыдущего результата
; а это значит что только что мимо датчика проскочил пропуск на шкиву
; и этот результат мы не будем сохранять в качестве предыдущего
jnc tim_1_clr
; сохраняем значение таймера
mov R6,TL1
mov R7,TH1
tim_1_clr:
mov TL1,#0
mov TH1,#0
setb TR1 ; запускаем таймер, если двигатель был остановлен
sjmp sync_branch
; далее абсолютно аналогичный кусок для второго таймера
tim_0_rdy_int:
push PSW
push ACC
push B
push DPL
mov PSW,#08h
mov A,R2
add A,TL0
mov R2,A
mov A,R3
addc A,TH0
mov R3,A
clr A
addc A,R4
mov R4,A
mov A,TL0
mov B,sync_start_mult
mul AB
mov R5,B
mov A,TH0
mov B,sync_start_mult
mul AB
add A,R5
cpl A
mov R5,A
clr A
addc A,B
cpl A
xch A,0Dh
add A,R6
mov A,R5
addc A,R7
jnc tim_0_clr
mov R6,TL0
mov R7,TH0
tim_0_clr:
mov TL0,#0
mov TH0,#0
setb TR0 ; запускаем таймер, если двигатель был остановлен
sync_branch:
mov A,R0
jc no_sync ; если обнаружили пропуск
cpl rev_parity_flag ; инвертируем бит номера оборота для фазированного режима
; ставим флаг синхронизации
setb sync_reach_flag
; номер зуба - 0
mov R0,#0h
; если номер зуба не равен 0 - сбой синхронизации, прыгаем на его обработчик
cjne A,#0,sync_fail
sjmp no_sync
sync_fail:
; вероятно поймали короткую импульсную помеху, и сохранённый период между импульсами
; очень короткий, пишем максимальный период между импульсами
mov R6,#0FFh
mov R7,#0FFh
setb sync_err_flag ; ставим флаг ошибки синхронизации
clr A
no_sync:
; получаем "симметричный" номер зуба для разных групп цилиндров (1-4 и 2-3)
; находим остаток от деления полного номера зуба на половину зубов шкива (30)
mov B,sync_half_num
div AB
mov C,A.0
mov rev_half_flag,C
mov A,B
mov R1,A
; теперь в аккумуляторе "симметричный" номер, а в флаге rev_half_flag
; указатель на текущую "половину" (0 - первая половина оборота, 1 - вторая)
jnz ignition_test ; в начале половины оборота происходит обновление переменных
mov ign_num,ign_num_temp
mov ign_offset,ign_offset_temp
mov fuel_num,fuel_num_temp
ignition_test:
; проверяем на какой зуб назначено зажигание, самый приоритетный процесс
cjne A,ign_num,fuel_test ; если тут...
jb redline_ign_flag,fuel_test ; если не ограничены оборотами...
jnb sync_reach_flag,fuel_test ; и если есть синхронизация...
; вычисляем смещение для таймера из актуального периода между зубами шкива
; в процессе умножения к результату прибавится единица, чтобы таймер мог правильно
; отработать смещение равное 0 (если записать в ВИ53 0 - он будет считать 65536 тактов)
; при смещении равном 0 таймер отсчитает 1 такт и выдаст искру
mov B,ign_offset
mov A,R6
mul AB
mov R5,B
mov B,ign_offset
mov A,R7
mul AB
setb C ; +1
addc A,R5
mov R5,A
clr A
addc A,B
xch A,0Dh
; теперь в аккумуляторе младший байт
; а в регистре R5 - старший
; пишем смещение в таймер
mov DPL,#04h
movx @DPTR,A
mov A,R5
movx @DPTR,A
; запись по этому адресу взводит схему разрешения счёта, которая
; в свою очередь запускает таймер на ближайшем импульсе с ДПКВ
; в конце отсчёта СРАЗУ выдаётся искра и запускается таймер на рассыпухе,
; отсчитывающий длительность открытого состояния ключа для поддержания
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

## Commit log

2026-06-29 Slave board schematic fix
    [adc_board_fixed_prod.drl, slave_cpu_board_fixed.drl]
2026-06-30 ADC board schematic fix
2026-06-30 Schematic fix
